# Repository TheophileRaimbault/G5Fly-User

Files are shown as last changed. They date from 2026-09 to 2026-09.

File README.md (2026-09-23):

# G5Fly NXP-MCXA154

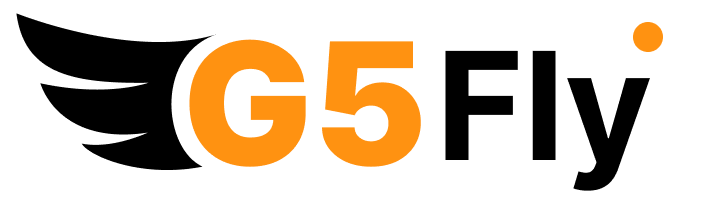
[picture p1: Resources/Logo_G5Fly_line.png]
G5Fly logo


Open-source GNSS navigation board for drones and robotics.

G5Fly is a compact board built around the Septentrio Mosaic-G5 module for lightweight UAV, robotics, and navigation projects. The repository contains the hardware design files, firmware sources, and supporting documentation needed to use the board, manufacture it, or create a custom derivative.

Author: <a href="https://github.com/TheophileRaimbault">Théophile Raimbault</a><br>
Maintainer: Septentrio GNSS GitHub user <githubuser@septentrio.com><br>
External website: https://github.com/septentrio-gnss/G5Fly<br>
License: <a href="https://creativecommons.org/licenses/by-sa/4.0/">Creative Commons Attribution-ShareAlike 4.0</a> and <a href="https://www.oshwa.org/definition/">Open Source Hardware</a><br>

<div style="background-color:#e3f2fd; border-left:5px solid #1976D2; padding:10px; border-radius:5px; margin-top:10px;">
  ℹ️ <strong>Note:</strong> G5Fly is optimized for a 30.5 x 30.5 mm FPV drone form factor and is intended for open source drone or robot projects.
</div><br>

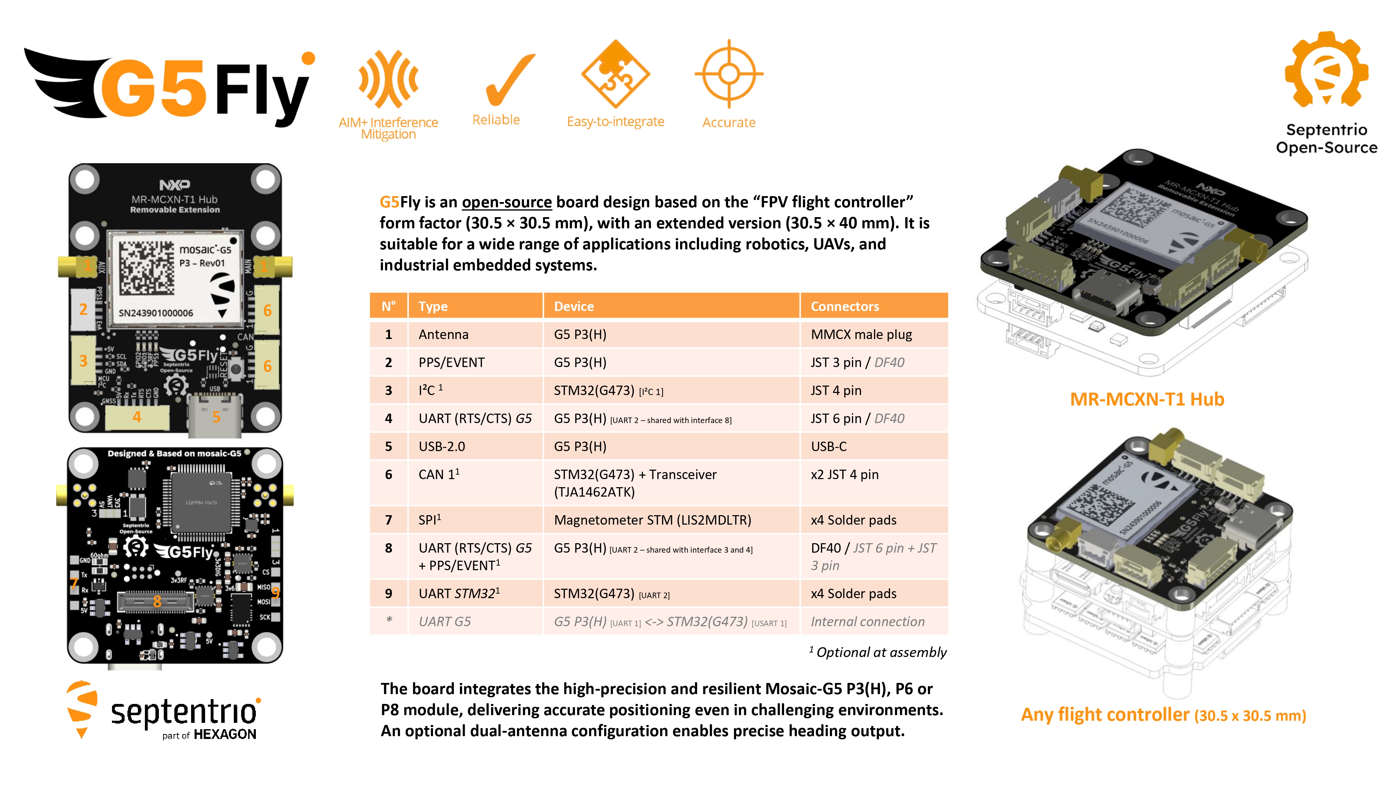
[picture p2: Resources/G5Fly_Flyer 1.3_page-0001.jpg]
<br>

## Who is this repository for?

This project serves two audiences:

- Users who want to buy, assemble, or use the board as-is.
- Designers who want to understand the hardware in detail and create a custom version.

If you are a user, start with the sections below. If you want to modify the design, go to [DESIGN.md](DESIGN.md).

## For users

### Key features
- Compact 30.5 x 30.5 mm FPV-friendly form factor
- Septentrio Mosaic-G5 GNSS receiver support
- USB and external 5 V power options
- DroneCAN, TTL, serial and I2C interfaces
- Reset input and status LEDs
- Mezzanine connection for the [NXP MCXN T1 hub](https://github.com/NXP-Robotics/mr_mcxn_t1_hub)

### Feature - Mezzanine integration with the NXP MCXN T1 hub

The G5Fly can be connected through its mezzanine interface to the [NXP MCXN T1 hub](https://github.com/NXP-Robotics/mr_mcxn_t1_hub). This provides a hardware expansion path for robotics applications. Refer to the [NXP integration HW-FW document](Resources/NXP%20integration%20HW-FW.pptx) for the hardware and firmware integration details.

<p align="center">
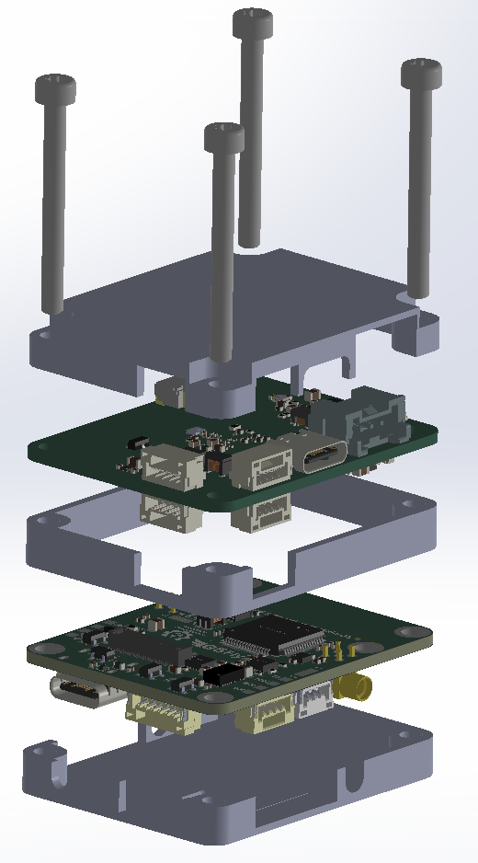
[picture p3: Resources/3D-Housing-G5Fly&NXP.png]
3D housing integrating the G5Fly and NXP MCXN T1 hub
  
</p>

### Quick start
1. Use the current production design files in [hardware/versions/v1/kicad/production](hardware/versions/v1/kicad/production/) if you want to build the board without changing the design.
2. Connect a suitable GNSS antenna and power the board through USB or an external 5 V source.
3. Develop and flash your application using the [Zephyr Project](https://www.zephyrproject.org/). No application software is currently provided by default.
4. Use the available UART, I2C, or DroneCAN interfaces depending on your integration target.
5. Validate the board with the status LEDs and the expected GNSS fix behavior before full integration.

### Antenna power selection
- Power can be supplied by USB or from an external 5 V rail.
- Active antennas must be powered at the voltage specified by the antenna manufacturer.

<div style="background-color:#ffebee; border-left:5px solid #c62828; padding:10px; border-radius:5px; margin:10px 0;">
  <strong>Warning:</strong> Solder <code>JP1</code> before using an active antenna. If the jumper is left open, the <code>VANT</code> net is not powered and the antenna may not work, causing a significant loss of GNSS performance. Select only one voltage, according to the antenna datasheet.
</div>

<table>
  <tr>
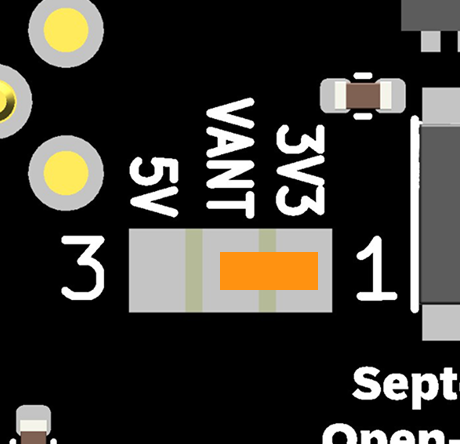
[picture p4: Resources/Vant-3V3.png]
JP1 configured for 3.3 V antenna power
    <td align="center"><br><strong>3.3 V antenna</strong><br>Connect <code>VANT</code> to <code>+3.3V_RF</code>.</td>
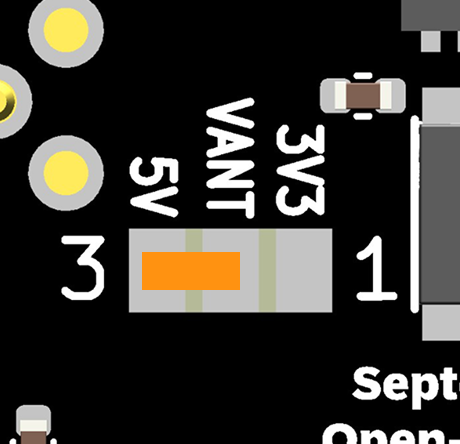
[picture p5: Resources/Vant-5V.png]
JP1 configured for 5 V antenna power
    <td align="center"><br><strong>5 V antenna</strong><br>Connect <code>VANT</code> to <code>+5V</code>.</td>
  </tr>
</table>

### Production and manufacturing
For a production build without hardware changes:

- Use the current KiCad project and generated manufacturing files from the hardware folder: [hardware/versions/v1/kicad](hardware/versions/v1/kicad/)
- Provide the manufacturer with the schematic, PCB files, BOM, and CPL.
- Verify antenna connector type, jumper configuration, and power options before assembly.
- Reference schematic: [Resources/G5Fly-schematics-NXP.pdf](Resources/G5Fly-schematics-NXP.pdf)

#### JLCPCB manufacturing requirements

- Keep the default KiCad PCB setup and its calculated impedance settings.
- Manufacture the board as a 6-layer PCB.
- `PCB Requirement: User.1 layer should be used as the V-cut guide layer.`
- Refer to the detailed [PCB rules](Resources/PCB_rules.png) when preparing or reviewing the PCB for production.
- For a production run at JLCPCB, use the [G5Fly_NXP_Rev-2_JLCPCB production archive](hardware/versions/v1/kicad/production/G5Fly_NXP_Rev-2_JLCPCB.zip), which contains the files prepared and previously submitted to JLCPCB for manufacturing.

### Power and antenna
- Keep GNSS antenna cables away from noisy power traces where possible.

### Recommended antenna options
The following antenna families are commonly considered for evaluation:

- D-Helix antenna HX-CHX600A
- D-Helix antenna HX-CH7609A
- HC990EXF Calian antenna

A SMA-to-MMCX adapter is often useful for compatibility with the board connector.

## For designers and contributors

The detailed hardware design guide is available in [DESIGN.md](DESIGN.md).

That document covers:
- Overall architecture and major blocks
- Component selection and board organization
- How to create a custom derivative board
- Manufacturing and validation recommendations
- Suggested workflows for changing the hardware safely

## Repository structure
- [hardware](hardware): PCB sources, KiCad projects, and mechanical assets
- [firmware](firmware): firmware and configuration files
- [Resources](Resources): images, schematics, and support documents
- [docs](docs): additional notes and guidance

## Licensing
This project is released under the Creative Commons Attribution-ShareAlike 4.0 license and follows the Open Source Hardware definition.

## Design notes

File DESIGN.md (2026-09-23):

# G5Fly NXP-MCXA154 hardware design guide

This document is for contributors who need to understand or modify the NXP hardware design.

## 1. Purpose of this document

Use this guide to locate the important hardware references, modify the KiCad project, and prepare a checked production release.

## 2. Project overview

G5Fly is a 30.5 x 30.5 mm GNSS board built around the Septentrio mosaic-G5 and an NXP MCXA154. The MCXA154 is intended to run a user application built with Zephyr; no application firmware is supplied by default.

## 3. Repository structure

Start with these locations:

- [hardware/versions/v1/kicad](hardware/versions/v1/kicad): the current KiCad project
- [hardware/versions/v1/kicad/production](hardware/versions/v1/kicad/production): production exports
- [hardware/common/libraries](hardware/common/libraries): project symbols, footprints, and 3D models
- [hardware/common/design_rules/design-rules.md](hardware/common/design_rules/design-rules.md): track, via, and clearance values
- [Resources/G5Fly-schematics-NXP.pdf](Resources/G5Fly-schematics-NXP.pdf): schematic PDF
- [VERSIONING.md](VERSIONING.md): changes between hardware revisions

## 4. Hardware architecture
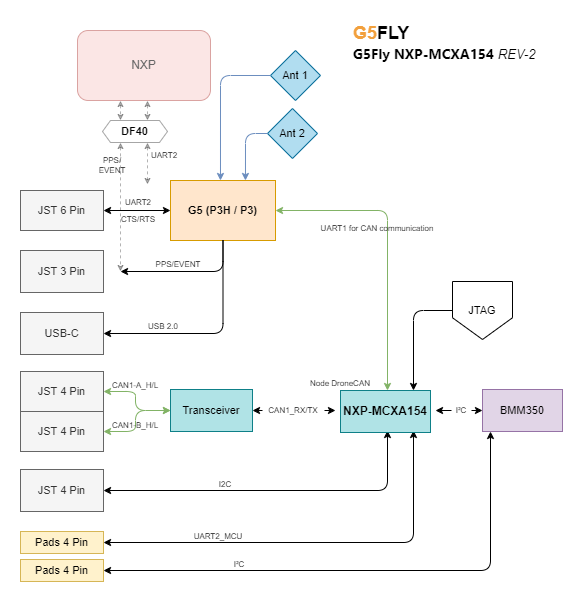
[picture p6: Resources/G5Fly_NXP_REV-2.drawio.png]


*Functional block diagram of the G5Fly NXP-MCXA154 REV-2, showing the Mosaic-G5 receiver, MCXA154, BMM350 magnetometer, CAN transceiver, antenna connections, and the main UART, I2C, PPS, USB, and expansion interfaces.*

### 4.1 Main functional blocks

The board can be understood through the following main components. Their references correspond to the [G5Fly NXP Rev-2 BOM](hardware/versions/v1/kicad/production/G5Fly_NXP_Rev-2_bom.csv):

| Function | Reference | Component | Role |
| --- | --- | --- | --- |
| GNSS receiver | `U1` | Septentrio mosaic-G5 | Main GNSS receiver |
| Microcontroller | `IC1` | NXP MCXA154VLH | Runs the Zephyr application |
| Magnetometer | `U4` | Bosch BMM350 | Magnetic-field measurement |
| CAN transceiver | `U3` | NXP TJA1462ATK | Physical-layer interface for DroneCAN/CAN |
| Main power regulation | `U8` | MPM3632CGQV-Z | Main switching regulator |
| Low-noise regulation | `U7`, `U12` | TPS7A9401DSCR | Low-noise regulated power rails |
| Antenna power selection | `JP1` | 3-position solder jumper | Selects antenna power between `+3.3V_RF` and `+5V` |

### 4.2 Connectors and configuration points

The board exposes the following connectors and configuration points. Their references correspond to the schematic and the [G5Fly NXP Rev-2 BOM](hardware/versions/v1/kicad/production/G5Fly_NXP_Rev-2_bom.csv):

| Interface or function | Reference | Connector or component | Role |
| --- | --- | --- | --- |
| PPS and event interface | `J1` | JST-SM03B-GHS | Ground, PPS input and event signal |
| GNSS serial interface | `J4` | JST-SM06B-GHS | GNSS UART, 5 V power and ground |
| Magnetometer interface | `J7` | JST-SM04B-GHS | I2C connection to the magnetometer or an external sensor |
| CAN interface | `J6`, `J9` | JST-SM04B-GHS | DroneCAN/CAN connection and power |
| Main GNSS antenna | `J10` | MMCX connector | Main antenna RF connection |
| Auxiliary GNSS antenna | `J11` | MMCX connector | Auxiliary antenna RF connection |
| USB | `J3` | USB-C receptacle | USB communication and board power |
| Mezzanine expansion | `J8` |  [DF40 board-to-board connector](Resources/Connector-DF40.png)| High-density expansion interface  |
| Programming and debug | `J5` | Tag-Connect TC2030 | SWD programming and debug access |
| Antenna power selection | `JP1` |  [3-position solder jumper](Resources/Vant-5V.png)| Selects antenna power between `+3.3V_RF` and `+5V` |
| Reset | `SW3` | Push button | Resets the MCXA154 |

## 5. Modification workflow

### Step 1: Create a new hardware revision

Copy [hardware/versions/v1](hardware/versions/v1) to a new revision directory before making a hardware change. Keep released revisions unchanged. Record the change in [VERSIONING.md](VERSIONING.md).

### Step 2: Change the schematic first

Open `hardware/versions/v1/kicad/G5FLY.kicad_pro` and modify `G5FLY.kicad_sch` before editing the PCB. For every changed component, check its pin mapping, footprint, value, and datasheet. Pay particular attention to the GNSS RF path, `VANT`, the MCXA154 pin assignment, the I2C magnetometer bus, and the CAN transceiver.

### Step 3: Update and review the PCB

Update the PCB from the schematic, then review the board outline, connector orientation, antenna connectors, magnetometer orientation, copper clearances, and power paths. Do not replace project-library parts with global KiCad libraries; follow [Guidline.md](Guidline.md).

### Step 4: Run checks before export

Run ERC on the schematic and DRC on the PCB. Resolve errors, or document an intentional exception before continuing. Confirm that the schematic, PCB, BOM, and designators describe the same revision.

### Step 5: Prepare production files

Before sending the board for manufacturing, prepare:

- schematic export or PDF,
- KiCad project archive or source files,
- BOM,
- CPL/placement file,
- Gerbers and drill files,
- assembly notes for connectors, jumpers, and antennas.

<div style="background-color:#fff8e1; border-left:5px solid #f9a825; padding:10px; border-radius:5px; margin-top:10px;">
	<strong>Tip:</strong> It is recommended to use the KiCad Fabrication Toolkit to extract the fabrication files, including the Fab BOM and CPL, in the format required for production by JLCPCB.
</div>

## 6. Checks specific to this board

### 6.1 RF and antenna layout

- keep the antenna path short and direct,
- keep switching and high-speed digital traces away from the GNSS RF path,
- verify the two MMCX connectors (`J10` and `J11`) and their ground connection,
- antenna power is routed through pad 2 of `JP1` on the `VANT` net; `JP1` selects `+3.3V_RF` or `+5V`.

<div style="background-color:#ffebee; border-left:5px solid #c62828; padding:10px; border-radius:5px; margin:10px 0;">
	<strong>Warning:</strong> JP1 must be soldered for the required antenna voltage. If the jumper is left open, the <code>VANT</code> net is not powered and an active antenna may not work, causing a significant loss of GNSS performance.
</div>

The solder bridge must connect the centre `VANT` pad to the voltage required by the antenna. Select only one configuration, according to the antenna datasheet:

<table>
	<tr>
		<td align="center">JP1 configured for 3.3 V antenna power<br><strong>3.3 V antenna</strong><br>Solder the bridge between `VANT` and `+3.3V_RF`.</td>
		<td align="center">JP1 configured for 5 V antenna power<br><strong>5 V antenna</strong><br>Solder the bridge between `VANT` and `+5V`.</td>
	</tr>
</table>

- verify the selected antenna voltage against the antenna datasheet before assembly.

### 6.2 Power integrity

- preserve the existing separation between digital, RF, and low-noise regulated rails,
- verify the ratings and output voltages of `U8`, `U7`, and `U12` after any power-tree change,
- check the USB and external 5 V paths for reverse-current or short-circuit risks,
- use the track widths and via sizes defined in [design-rules.md](hardware/common/design_rules/design-rules.md).

### 6.3 Mechanical integration

- preserve the 30.5 x 30.5 mm board outline unless creating a new derivative,
- confirm clearance around `J3`, `J8`, `J10`, and `J11`,
- keep the magnetometer clear of ferromagnetic parts and high-current paths,
- check connector access against the intended enclosure or frame.

## 7. Release checklist

Before sending a revision to production:

- confirm the revision identifier and update [VERSIONING.md](VERSIONING.md),
- run schematic ERC and PCB DRC,
- verify that every schematic component has a project-library symbol and footprint,
- verify that all 3D models use relative paths,
- compare the BOM and designator list with the final schematic and PCB,
- inspect `J3`, `J5`, `J6`, `J7`, `J8`, `J9`, `J10`, `J11`, `JP1`, and `SW3`,
- verify antenna power selection and connector orientation,
- generate Gerbers, drill files, Fab BOM, and CPL with the Fabrication Toolkit,
- open the generated files or use the manufacturer preview before ordering,
- record the validation result and any intentional exceptions.

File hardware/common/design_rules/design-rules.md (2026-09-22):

Track width :

    Power : 0.5
    Smal Power : 0.3
    Signal : 0.2

Via size :

    hole : 0.3
    size : 0.5

Change applied : 

    Minimum Track width: 0.25 to 0.15
    Minimum annular width : 0.2 to 0.15
    Coper to eadge Clearance : 0.3 to 0.2

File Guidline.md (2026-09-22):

***

# Library Management

## Overview

All project components are centralized in a single library to ensure portability, reproducibility, and ease of maintenance.

```
hardware/common/libraries/
├── symbols/
│   └── G5FLY.kicad_sym
└── footprints/
    └── G5FLY.pretty/
```

All symbols and footprints used in the project must be defined in these libraries.  
External or global KiCad libraries must not be used.

***

## Adding a New Component

When introducing a new component (e.g., from JLCPCB, SnapEDA, UltraLibrarian), follow the process below.

### 1. Import and Validate

Import the symbol and footprint using the preferred method.  
Verify correctness before integration:

* Pin mapping
* Orientation
* Footprint dimensions
* Datasheet consistency

***

### 2. Add Symbol to Project Library

1. Open the Symbol Editor
2. Open the project library:
   ```
   G5FLY.kicad_sym
   ```
3. Open the imported symbol
4. Copy the symbol and paste it into `G5FLY.kicad_sym`

The library already exists; new components must be added to it, not recreated.

Apply a consistent naming convention:

```
R_10k_0603
C_100nF_0603
STM32G0_QFN32
USB_C_Receptacle
```

***

### 3. Add Footprint to Project Library

1. Open the Footprint Editor
2. Open the project footprint library:
   ```
   G5FLY.pretty
   ```
3. Copy the footprint and paste it into this library

Ensure consistency between symbol and footprint naming.

***

### 4. Add and Link 3D Model

All 3D models must be stored in:

```
hardware/common/3d_models/
```

Link the 3D model in the footprint using a relative path:

```
${KIPRJMOD}/../../../common/3d_models/component.step
```

Absolute paths must not be used.

***

### 5. Link Symbol, Footprint, and Fields

Ensure that:

* The symbol references the correct footprint
* The footprint references the correct 3D model
* Manufacturer or supplier fields are properly defined (e.g., LCSC ID)

***

### 6. Verify Library Consistency

In the schematic editor:

```
Tools → Edit Symbol Library Links
```

All components must reference:

```
G5FLY_lib
```

In the PCB editor:

```
Tools → Edit Footprint Library Links
```

Only the project footprint library should be used.

***

## Design Rules

The following rules apply to all components:

* Do not use global KiCad libraries (e.g., Device, Connector)
* Do not use absolute file paths
* Do not reference external plugin libraries directly
* Always copy components into the project libraries before use

***

# Version Management

## Directory Structure

Each hardware revision is stored independently:

```
hardware/versions/
├── v1/
├── v2/
└── v3/
```

Each version contains:

* KiCad project files
* Fabrication outputs
* Assembly notes
* Visual outputs

***

## Versioning Policy

### Immutable Releases

Released versions must not be modified after fabrication or validation.

Any change must result in a new version.

***

### Creating a New Version

To create a new revision:

```
cp -r v1 v2
```

All design modifications must be performed in the new version directory.

***

### Git Versioning

Each hardware revision must be tagged in Git:

```
v1.0
v2.0
```

Tags must correspond to manufacturable PCB versions.

***

### Recommended Workflow

* `main`: stable and released versions
* `dev`: ongoing development

Example:

```
git checkout -b dev
git commit -m "fix: correct pull-up resistor value"
git commit -m "feat: add ESD protection"
```

When ready:

```
git checkout main
git merge dev
git tag v2.0
```

***

## Fabrication Outputs

Each version must include complete manufacturing data:

```
fabrication/
├── gerbers/
├── bom/
├── pick_place/
```

This ensures that any version can be reproduced without ambiguity.

***

## Objective

The repository must guarantee that any user can:

```
git clone
open project in KiCad
generate outputs
manufacture the board
```

and obtain identical hardware.

***

## Summary

* Single, centralized project library
* No external dependencies
* Fully versioned hardware revisions
* Reproducible and traceable fabrication data
* Consistent and maintainable structure for long-term development

***

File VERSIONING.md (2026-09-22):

# Versioning and change log

This document summarizes the main hardware changes between G5Fly revisions.

## REV1 -> REV2

The following changes were applied for the transition from REV1 to REV2:

### Mechanical and layout
- Increased the spacing between the connector and the screw hole.
- Reduced the board size slightly to better match the NXP board footprint.
- Added the REV-1 reference on the silkscreen.
- Adjusted the LED spacing.

### Electrical and component updates
- Changed the I2C pull-up resistors to a more suitable value range (from 10 kΩ to a more appropriate 2.2–4.7 kΩ range).
- Corrected the main antenna grounding connection.
- Replaced the wrong resistor value R16 from 24 kΩ to 13 kΩ for production.
- Switched the magnetometer interface from SPI to I2C.
- Changed the CAN termination approach to a shunt-based solution.
- Updated the magnetometer component used for the NXP board compatibility.

### Connectors and interfaces
- Changed to the correct Hirose connector part number: DF40TC(2.5)-50DS-0.4V(51).
- Removed unused STM32 CTS/RTS pins from the schematic.
- Added a PPS signal from the GNSS to the STM32 for time synchronization.
- Added a CAN status LED.

### Firmware and identification
- Added an internal crystal oscillator.
- Added hardware board ID information in the ArduPilot board definition file.
- Added silkscreen orientation guidance for the magnetometer.

### Not implemented in REV2
The following ideas were considered but were not implemented in REV2:
- reversed diode protection,
- adding a reset button or reset pin for the G5,
- adding additional flash memory.

## Future versioning guidance

For each new revision, it is recommended to keep this file updated with:

- the revision number,
- the date or milestone,
- a short summary of the main changes,
- the list of items intentionally not implemented,
- any important impact on firmware or integration.

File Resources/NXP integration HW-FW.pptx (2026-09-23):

## G5Fly integration with NXP

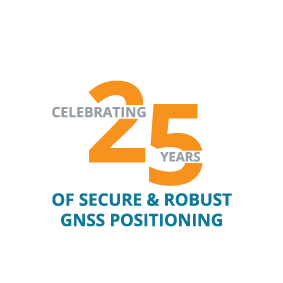
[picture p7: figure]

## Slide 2

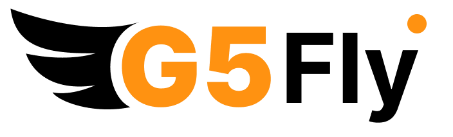
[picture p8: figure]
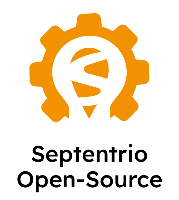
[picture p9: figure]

Hardware Integration with NXP

FPV GNSS based on NXP MCU

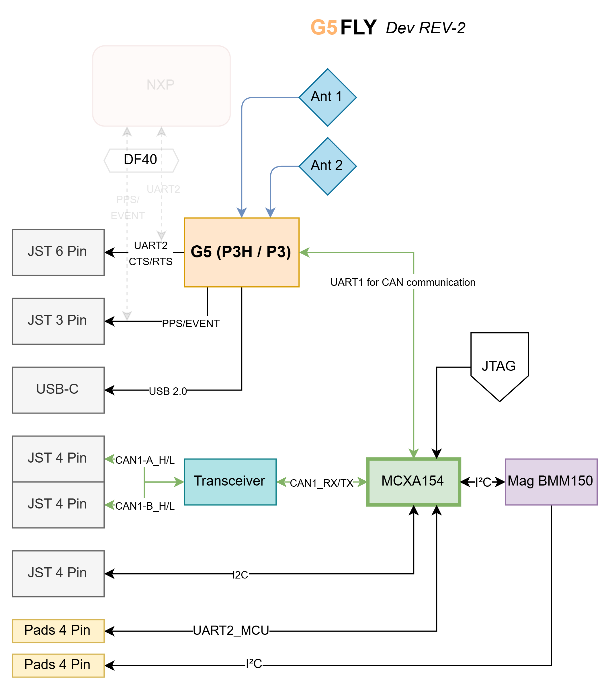
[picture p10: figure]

GNSS Tool for NXP MR-MCXN-T1 Hub

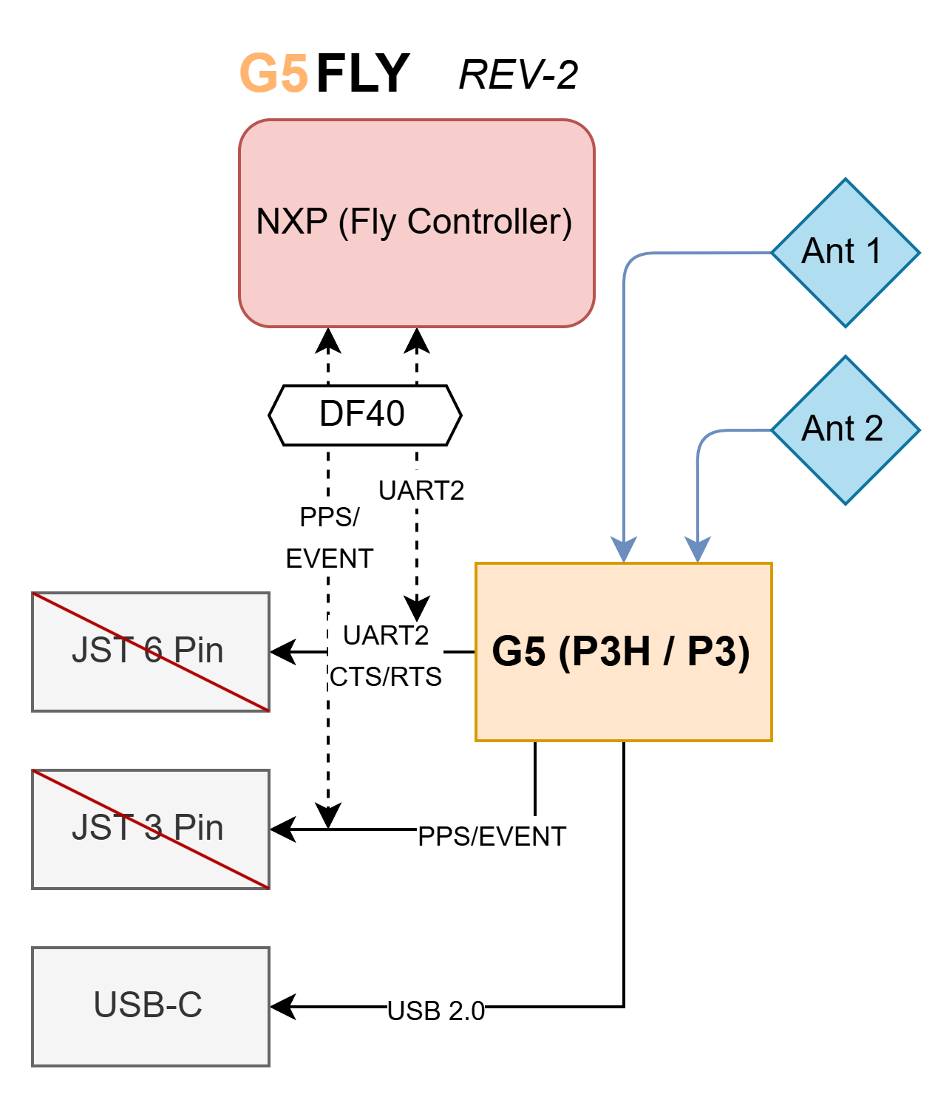
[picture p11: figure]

Unmonted component for MR-MCXN-T1 Hub

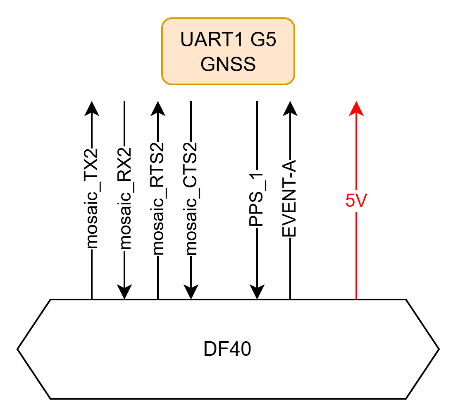
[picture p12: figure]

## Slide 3

Software Integration with NXP

FPV GNSS based on NXP MCU

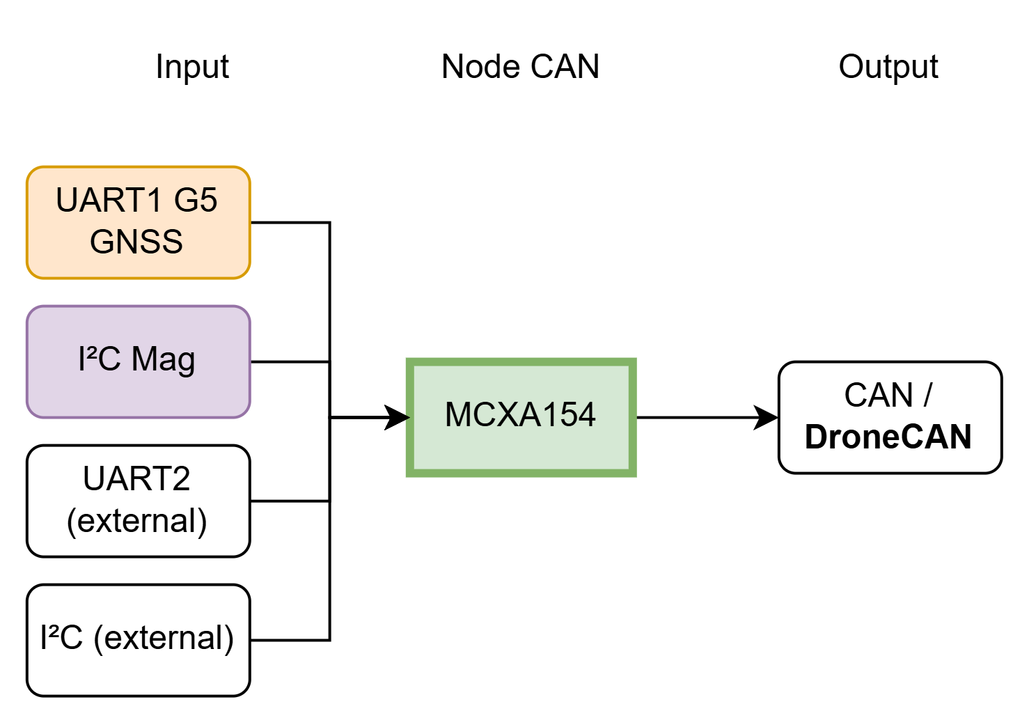
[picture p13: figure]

Need software capable of managing DroneCAN with SBF or NMEA + I²C Mag + other possible sensor inputs

GNSS Tool for NXP MR-MCXN-T1 Hub

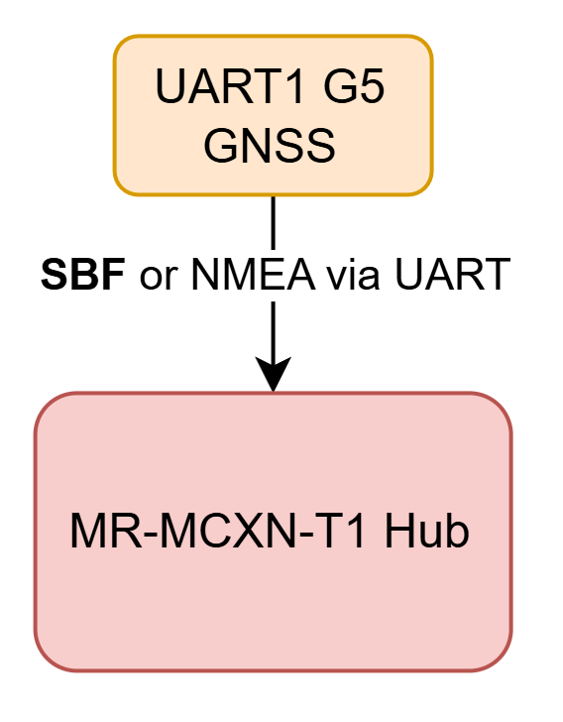
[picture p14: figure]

Need software capable of managing SBF or NMEA via UART

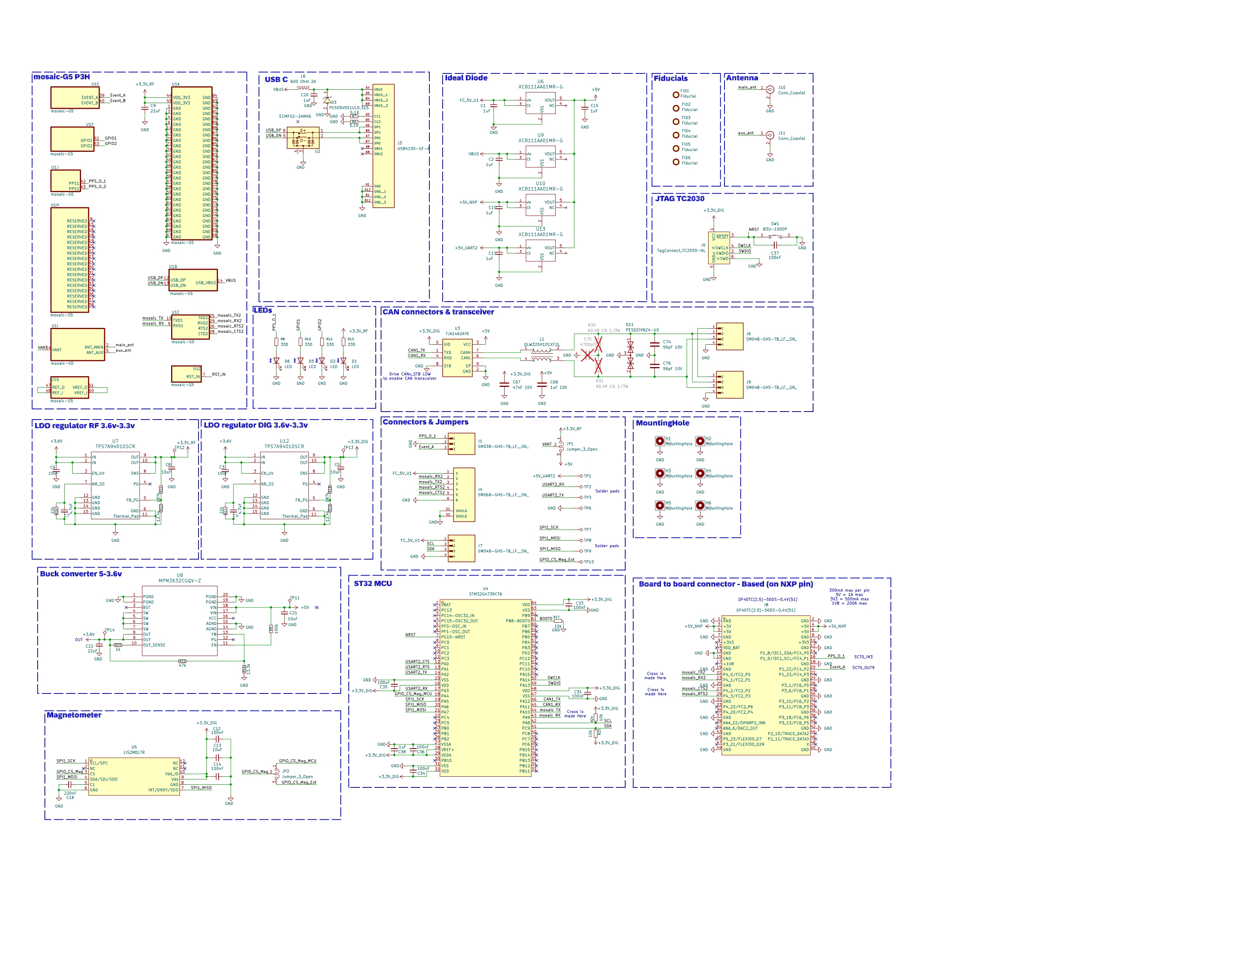
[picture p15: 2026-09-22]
Resources/G5Fly-schematics.jpg

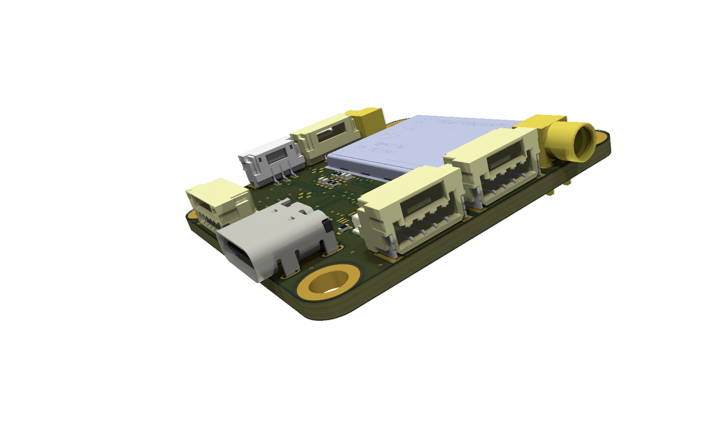
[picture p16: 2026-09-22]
Resources/G5FLY-3D-2.png

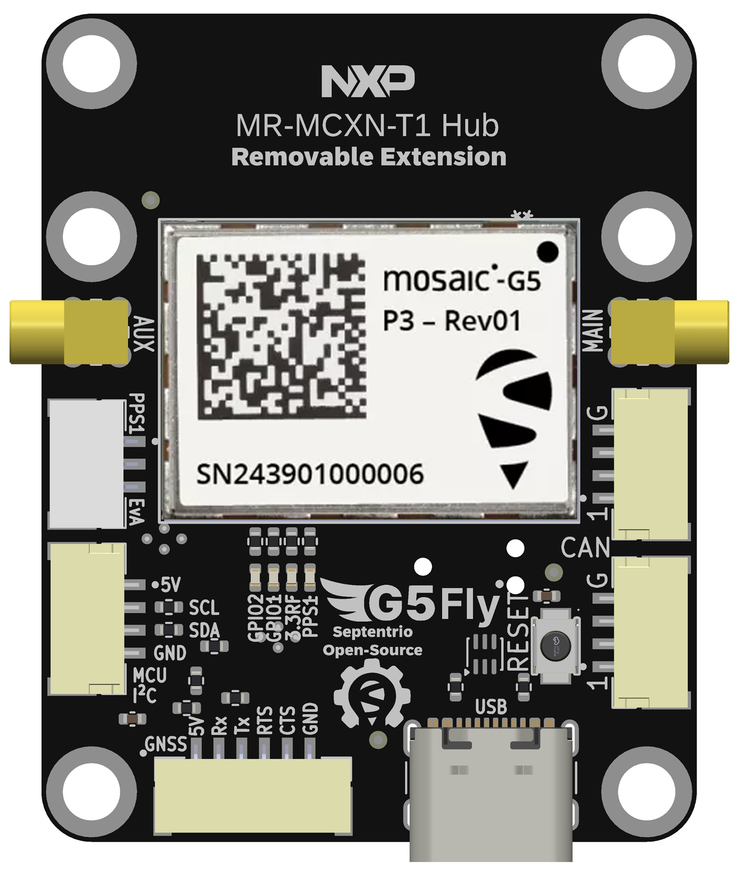
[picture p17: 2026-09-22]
Resources/Top_black_G5Fly.png

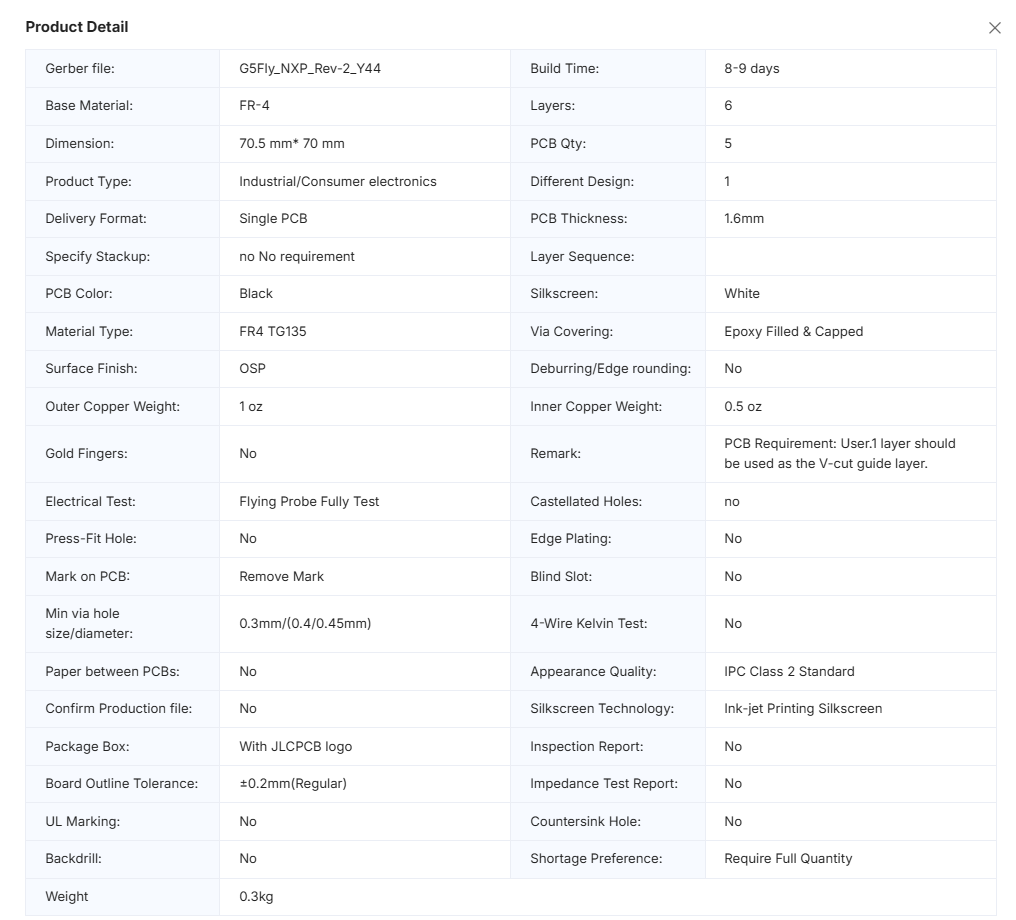
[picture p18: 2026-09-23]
Resources/PCB_rules.png

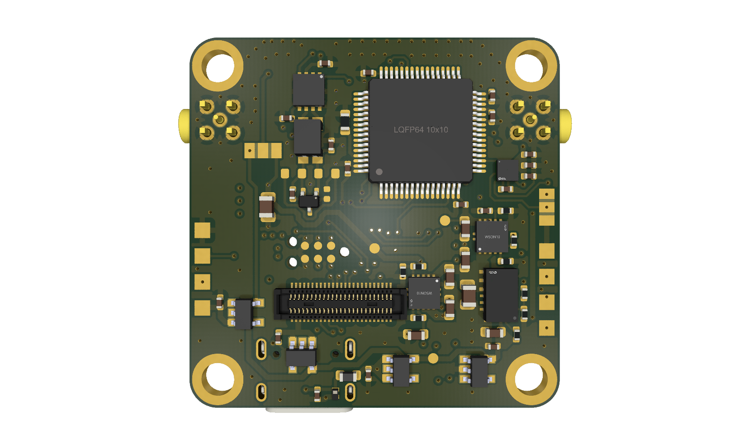
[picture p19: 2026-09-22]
Resources/G5FLY-Bot-ray.png

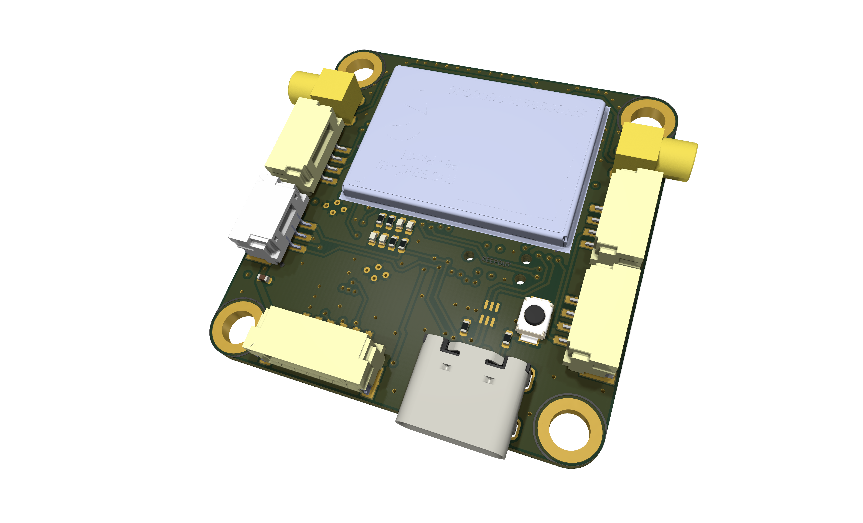
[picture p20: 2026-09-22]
Resources/G5FLY-3D.png

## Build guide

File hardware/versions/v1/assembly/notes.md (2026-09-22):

Placeholder for hardware/versions/v1/assembly/notes.md

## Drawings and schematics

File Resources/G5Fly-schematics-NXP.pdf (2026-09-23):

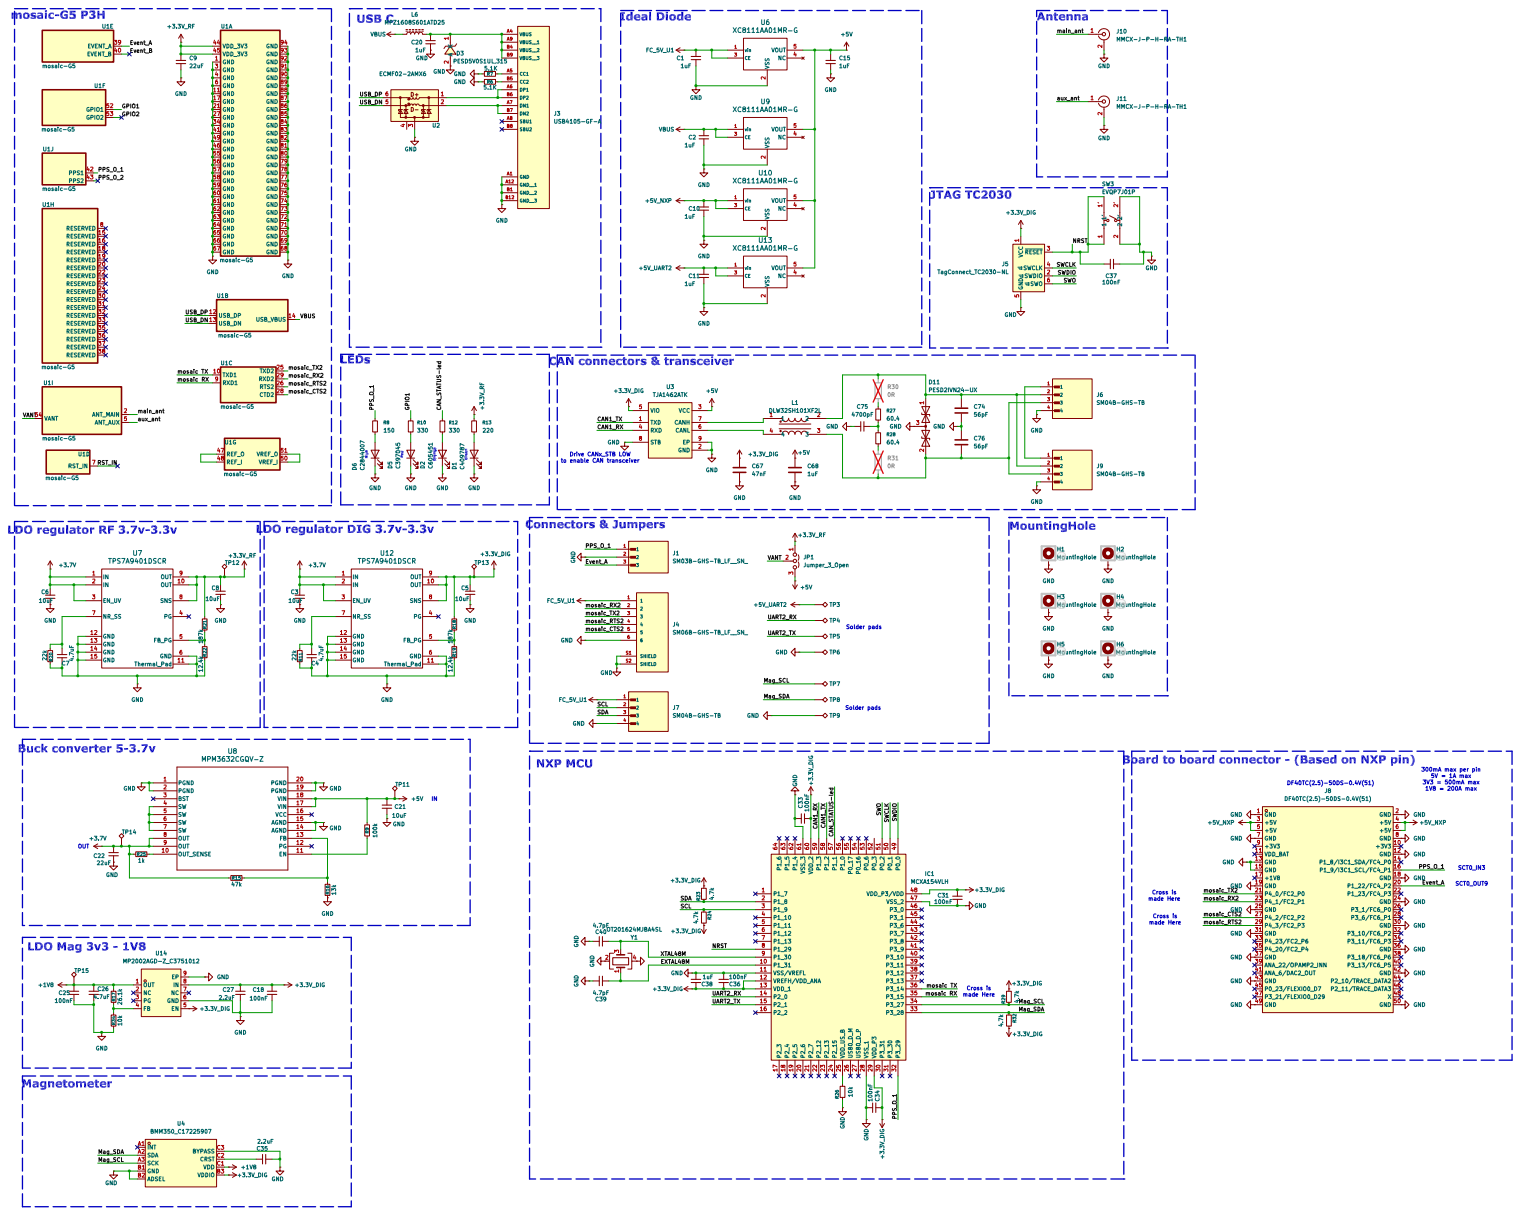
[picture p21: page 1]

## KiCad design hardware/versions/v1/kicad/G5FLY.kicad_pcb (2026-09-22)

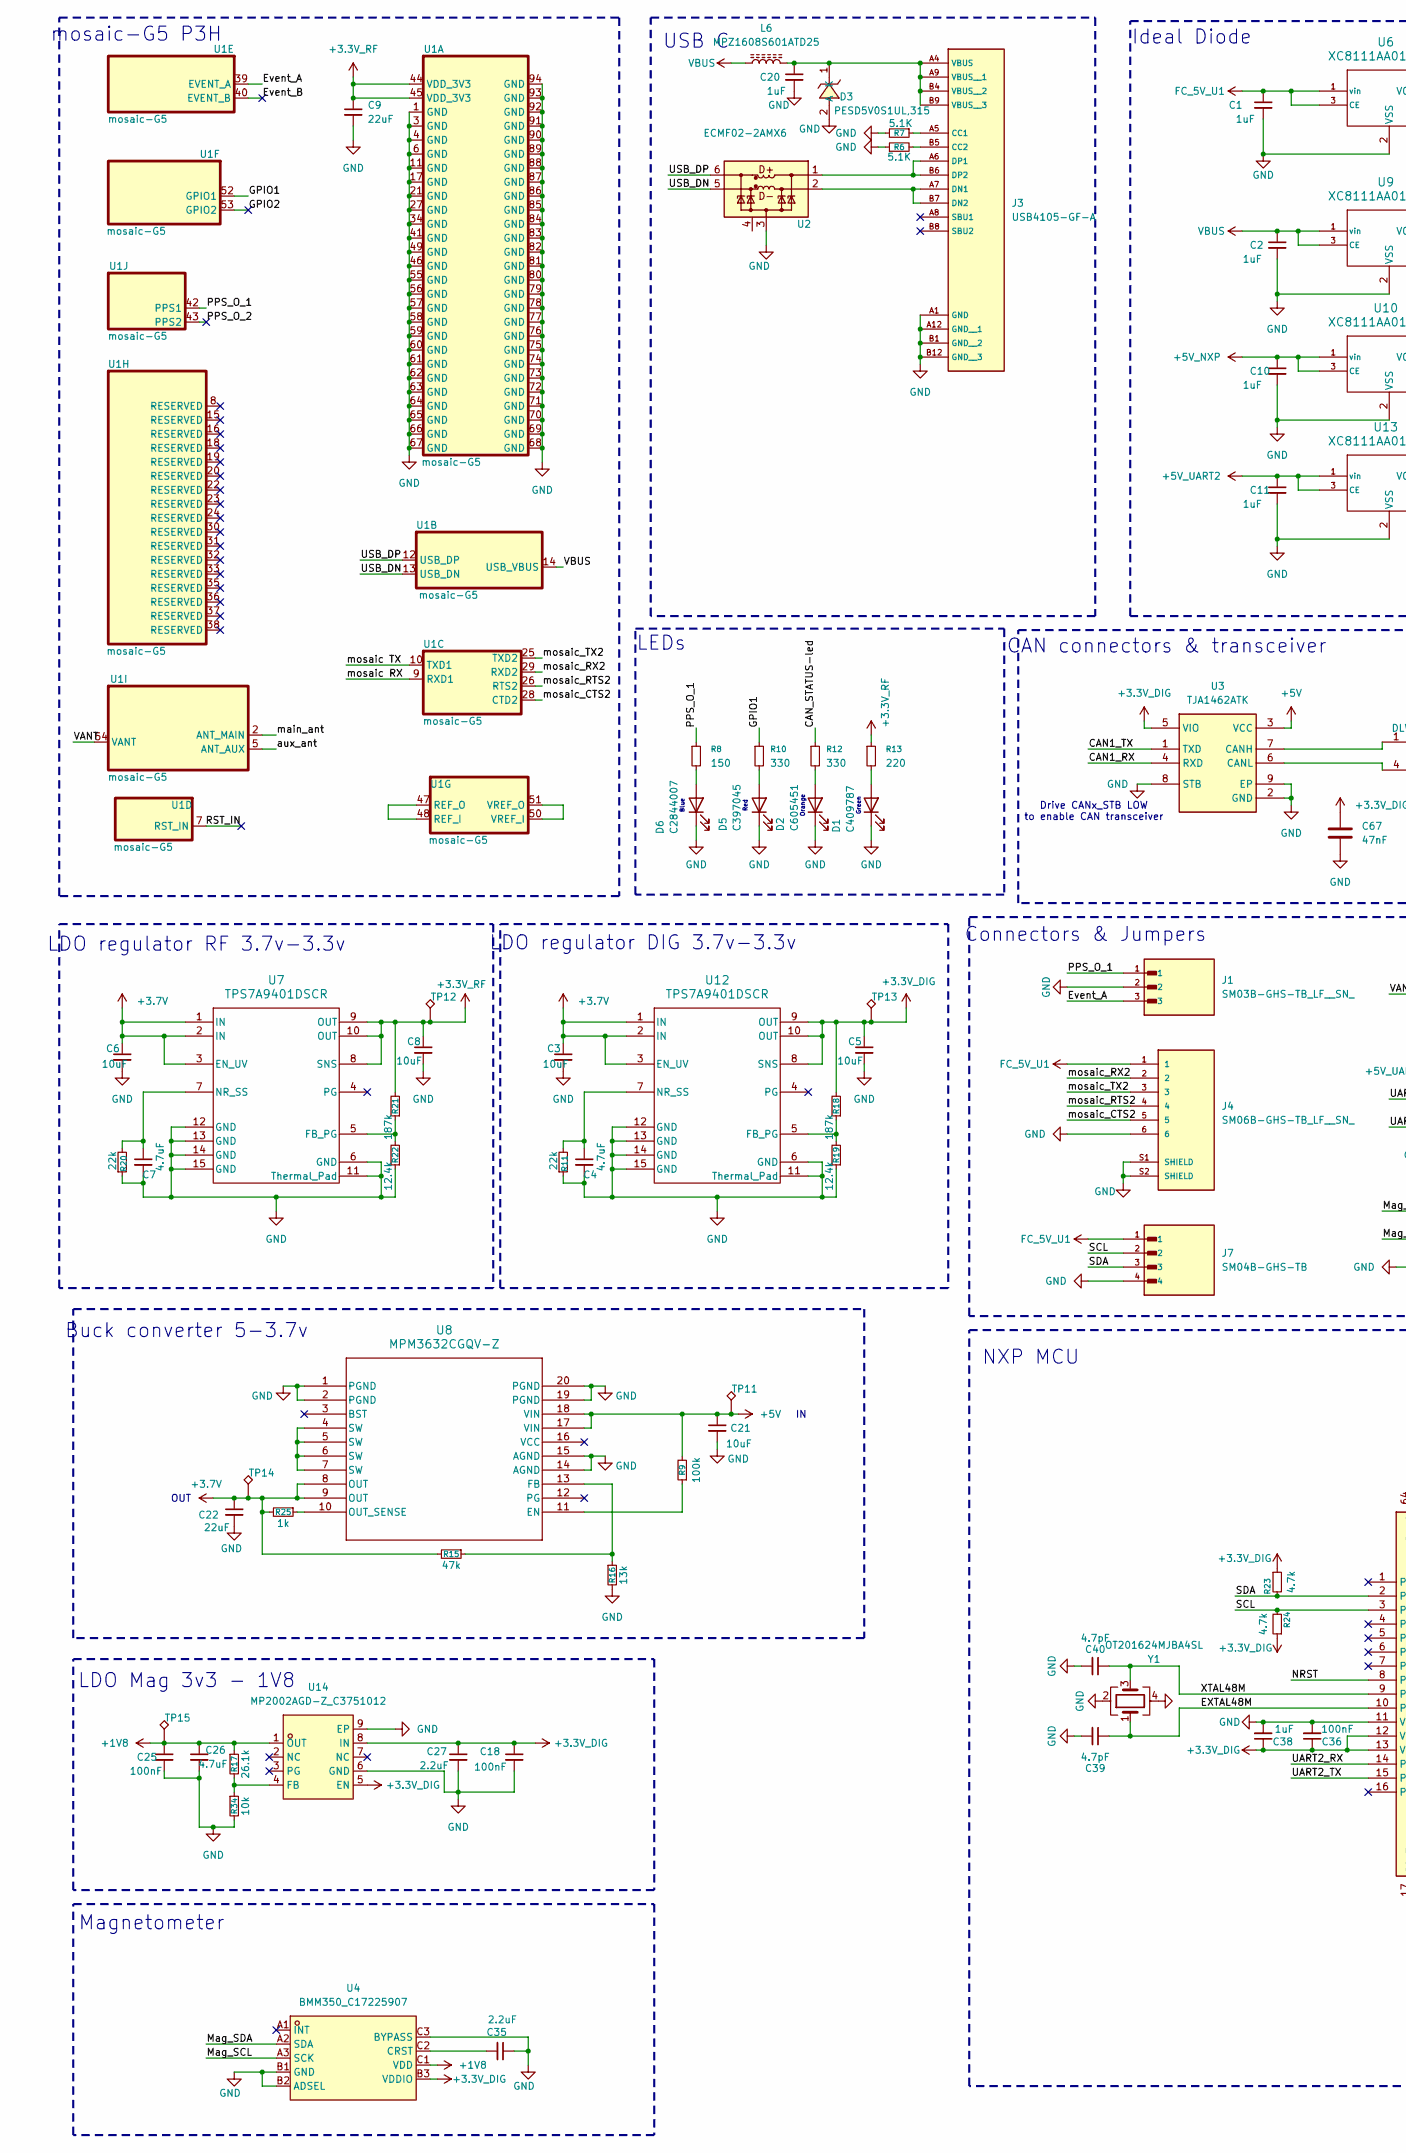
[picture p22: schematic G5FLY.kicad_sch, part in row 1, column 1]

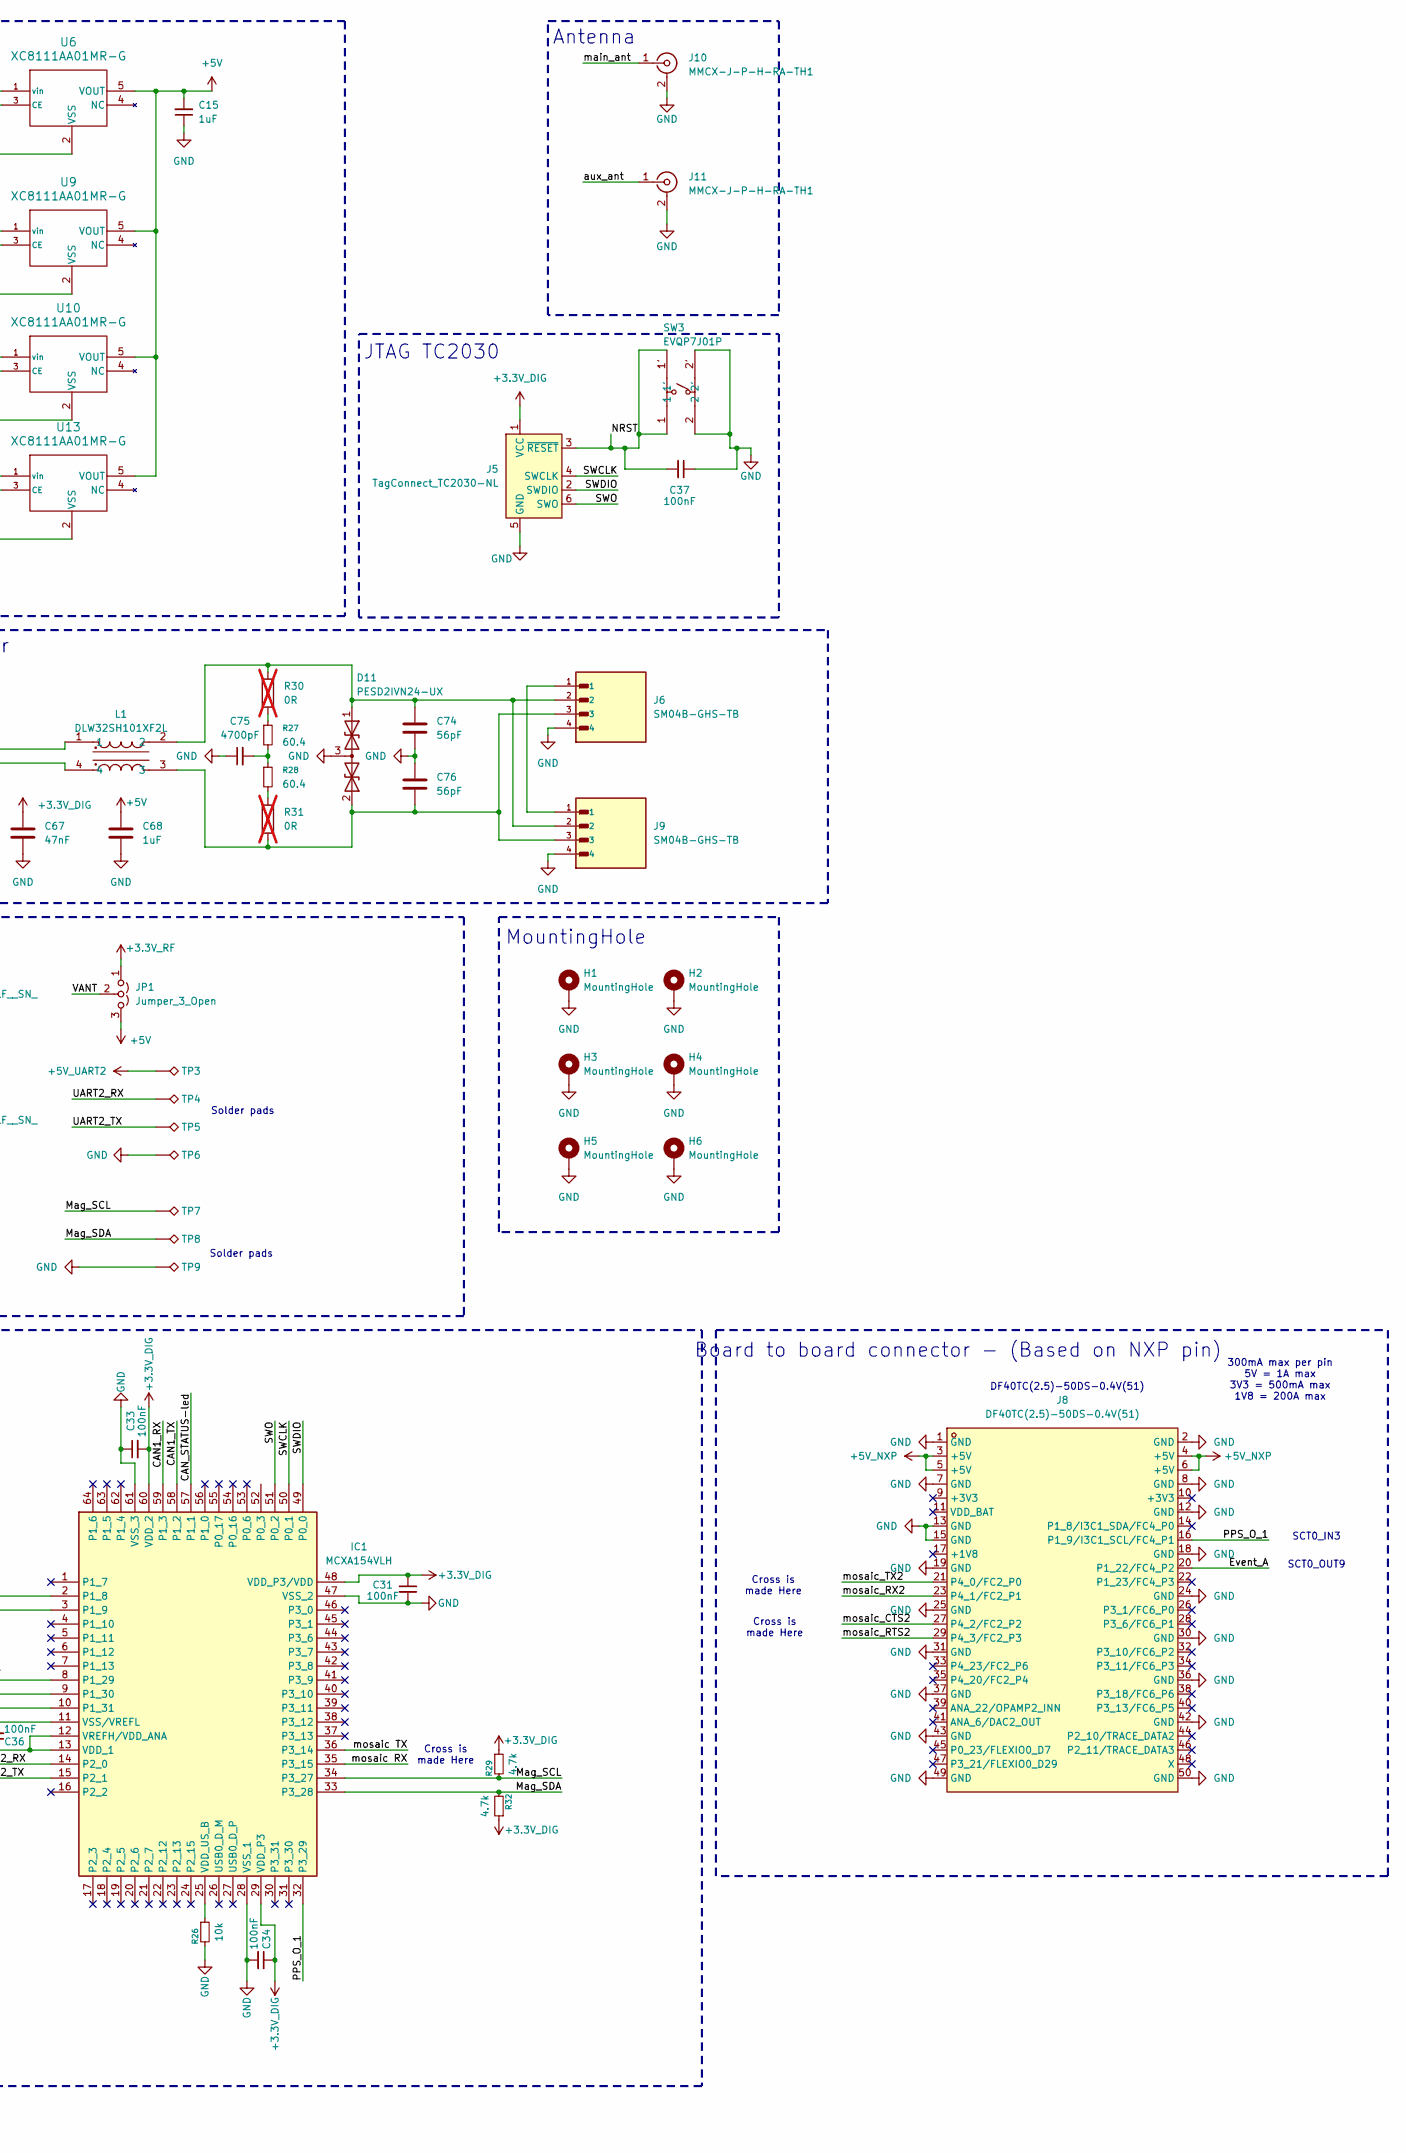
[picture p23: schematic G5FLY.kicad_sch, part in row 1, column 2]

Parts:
C1, C2, C10, C11, C15, C20, C38: 1uF; C_0402_1005Metric
C3, C5, C6, C8, C21: 10uF; C_0603_1608Metric
C4, C26: 4.7uF; C_0402_1005Metric
C7: 4.7uF; C_0603_1608Metric
C9, C22: 22uF; C_0805_2012Metric
C18, C25, C31, C33, C34, C36, C37: 100nF; C_0402_1005Metric
C27, C35: 2.2uF; C_0402_1005Metric
C39, C40: 4.7pF; C_0402_1005Metric
C67: 47nF; C_0402_1005Metric; JLCPCB C77012
C68: 1uF; C_0402_1005Metric; JLCPCB C528974
C74, C76: 56pF; C_0402_1005Metric; JLCPCB C107007
C75: 4700pF
D1: C409787; LED_0402_1005Metric; JLCPCB C409787
D2: C605451; LED_0402_1005Metric; JLCPCB C605451
D3: PESD5V0S1UL,315; SOD-882_L1.0-W0.6-RD; MPN PESD5V0S1UL,315; LCSC Part C85402
D5: C397045; LED_0402_1005Metric; JLCPCB C397045
D6: C2844007; LED_0402_1005Metric; JLCPCB C2844007
D11: PESD2IVN24-UX; SOT-323_SC-70; JLCPCB C552496
H1, H2, H3, H4, H5, H6: MountingHole; MountingHole_3.2mm_M3_DIN965_Pad
IC1: MCXA154VLH; QFP50P1200X1200X160-64N; Manufacturer_Part_Number MCXA154VLH
J1: SM03B-GHS-TB_LF__SN_; JST_SM03B-GHS-TB_LF__SN_
J3: USB4105-GF-A; USB_C_Receptacle_GCT_USB4105-xx-A_16P_TopMnt_Horizontal
J4: SM06B-GHS-TB_LF__SN_; JST_SM06B-GHS-TB_LF__SN_; PARTREV N/A
J5: TagConnect_TC2030-NL; Tag-Connect_TC2030-IDC-NL_2x03_P1.27mm_Vertical
J6, J7, J9: SM04B-GHS-TB; JST_SM04B-GHS-TB_LF__SN_
J8: DF40TC(2.5)-50DS-0.4V(51); CONN-SMD_DF40C-50DS-0.4V51; MPN DF40C-50DS-0.4V(51); LCSC Part C424646
J10, J11: MMCX-J-P-H-RA-TH1; SAMTEC_MMCX-J-P-H-RA-TH1; JLCPCB C2934607
JP1: Jumper_3_Open; SolderJumper-3_P1.3mm_Open_Pad1.0x1.5mm_NumberLabels
L1: DLW32SH101XF2L; FILTER-SMD_4P-L3.2-W2.5-BL_DLW32SH510XK2L; MPN DLW32SH101XF2L; LCSC Part C1857795
L6: MPZ1608S601ATD25; L_0603_1608Metric; DigiKey 445-MPZ2012S601ATD25CT-ND
R6, R7: 5.1K; R_0402_1005Metric
R8: 150; R_0402_1005Metric
R9: 100k; R_0402_1005Metric
R10, R12: 330; R_0402_1005Metric
R11, R20: 22k; R_0402_1005Metric
R13: 220; R_0402_1005Metric
R15: 47k; R_0402_1005Metric
R16: 13k; R_0402_1005Metric
R17: 26.1k; R_0402_1005Metric
R18, R21: 187k; R_0402_1005Metric
R19, R22: 12.4k; R_0402_1005Metric
R23, R24, R29, R32: 4.7k; R_0402_1005Metric
R25: 1k; R_0402_1005Metric
R26, R34: 10k; R_0402_1005Metric
R27, R28: 60.4; R_0402_1005Metric
R30, R31: 0R; R_0603_1608Metric; DigiKey 541-60.4SCT-ND; not fitted
SW3: EVQP7J01P; SW-SMD_EVQP7J01P; MPN EVQP7J01P; LCSC Part C2828254
TP3, TP4, TP5, TP6, TP7, TP8, TP9: TestPoint_Alt; TestPoint_Pad_1.5x1.5mm
TP11, TP12, TP13, TP14, TP15: TestPoint_Alt; TestPoint_Pad_D1.0mm
U1: mosaic-G5; LGA54_MOSAIC-MINI_SEP
U2: ECMF02-2AMX6; ST_UQFN-6L_1.5x1.7mm_P0.5mm
U3: TJA1462ATK; SON65P300X300X100-9N-D; JLCPCB C3229259
U4: BMM350_C17225907; WLCSP-9_L1.3-W1.3-R3-C3-P0.40-TL; MPN BMM350; LCSC Part C17225907
U6, U9, U10, U13: XC8111AA01MR-G; IC_XC8111AA01MR-G
U7, U12: TPS7A9401DSCR; DSC0010J-MFG
U8: MPM3632CGQV-Z; QFN3p0x5p0x1p6_MPM3632C_MNP
U14: MP2002AGD-Z_C3751012; QFN-8_L2.1-W3.1-P0.50-TL-EP; MPN MP2002AGD-Z; LCSC Part C3751012
Y1: OT201624MJBA4SL; Crystal_SMD_2016-4Pin_2.0x1.6mm; JLCPCB C725986

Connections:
+1V8: C25.1, C26.1, R17.1, TP15.1 (1_1), U4.C1 (VDD), U14.1 (OUT)
+3.3V_DIG: C5.1, C18.1, C27.1, C31.1, C33.2, C34.1, C36.1, C38.1, C67.1, IC1.12 (VREFH/VDD_ANA), IC1.13 (VDD_1), IC1.29 (VDD_P3), IC1.48 (VDD_P3/VDD), IC1.60 (VDD_2), J5.1 (VCC), R18.2, R23.1, R24.1, R29.1, R32.1, TP13.1 (1_1), U3.5 (VIO), U4.B3 (VDDIO), U12.8 (SNS), U12.9 (OUT), U12.10 (OUT), U14.5 (EN), U14.8 (IN)
+3.3V_RF: C8.1, C9.1, JP1.1 (A), R13.1, R21.2, TP12.1 (1_1), U1.44 (VDD_3V3), U1.45 (VDD_3V3), U7.8 (SNS), U7.9 (OUT), U7.10 (OUT)
+3.7V: C3.1, C6.1, C22.1, R15.2, R25.2, TP14.1 (1_1), U7.1 (IN), U7.2 (IN), U7.3 (EN_UV), U8.8 (OUT), U8.9 (OUT), U12.1 (IN), U12.2 (IN), U12.3 (EN_UV)
+5V: C15.2, C21.1, C68.1, JP1.3 (B), R9.2, TP11.1 (1_1), U3.3 (VCC), U6.5 (VOUT), U8.17 (VIN), U8.18 (VIN), U9.5 (VOUT), U10.5 (VOUT), U13.5 (VOUT)
+5V_NXP: C10.1, J8.3 (+5V), J8.4 (+5V), J8.5 (+5V), J8.6 (+5V), U10.1 (vin), U10.3 (CE)
+5V_UART2: C11.1, TP3.1 (1_1), U13.1 (vin), U13.3 (CE)
/CAN1_RX: IC1.59 (P1_3), U3.4 (RXD)
/CAN1_TX: IC1.58 (P1_2), U3.1 (TXD)
/CAN_STATUS-led: IC1.57 (P1_1), R12.1
/EXTAL48M: C39.1, IC1.10 (P1_31), Y1.1
/Event_A: J1.3, J8.20 (P1_22/FC4_P2), U1.39 (EVENT_A)
/Event_B: U1.40 (EVENT_B)
/GPIO1: R10.1, U1.52 (GPIO1)
/GPIO2: U1.53 (GPIO2)
/Mag_SCL: IC1.34 (P3_27), R29.2, TP7.1 (1_1), U4.A3 (SCK)
/Mag_SDA: IC1.33 (P3_28), R32.2, TP8.1 (1_1), U4.A2 (SDA)
/NRST: C37.2, IC1.8 (P1_29), J5.3 (~RESET), SW3.1, SW3.1'
/PPS_O_1: IC1.32 (P3_29), J1.1, J8.16 (P1_9/I3C1_SCL/FC4_P1), R8.1, U1.42 (PPS1)
/PPS_O_2: U1.43 (PPS2)
/RST_IN: U1.7 (RST_IN)
/SCL: IC1.3 (P1_9), J7.2, R24.2
/SDA: IC1.2 (P1_8), J7.3, R23.2
/SWCLK: IC1.50 (P0_1), J5.4 (SWCLK)
/SWDIO: IC1.49 (P0_0), J5.2 (SWDIO)
/SWO: IC1.51 (P0_2), J5.6 (SWO)
/UART2_RX: IC1.14 (P2_0), TP4.1 (1_1)
/UART2_TX: IC1.15 (P2_1), TP5.1 (1_1)
/USB_DN: U1.13 (USB_DN), U2.5 (D-_out)
/USB_DP: U1.12 (USB_DP), U2.6 (D+_out)
/VANT: JP1.2 (C), U1.54 (VANT)
/XTAL48M: C40.1, IC1.9 (P1_30), Y1.3
/aux_ant: J11.1 (In), U1.5 (ANT_AUX)
/main_ant: J10.1 (In), U1.2 (ANT_MAIN)
/mosaic RX: IC1.35 (P3_15), U1.9 (RXD1)
/mosaic TX: IC1.36 (P3_14), U1.10 (TXD1)
/mosaic_CTS2: J4.5, J8.27 (P4_2/FC2_P2), U1.28 (CTD2)
/mosaic_RTS2: J4.4, J8.29 (P4_3/FC2_P3), U1.26 (RTS2)
/mosaic_RX2: J4.2, J8.23 (P4_1/FC2_P1), U1.29 (RXD2)
/mosaic_TX2: J4.3, J8.21 (P4_0/FC2_P0), U1.25 (TXD2)
FC_5V_U1: C1.1, J4.1, J7.1, U6.1 (vin), U6.3 (CE)
GND: C1.2, C2.2, C3.2, C4.2, C5.2, C6.2, C7.2, C8.2, C9.2, C10.2, C11.2, C15.1, C18.2, C20.2, C21.2, C22.2, C25.2, C26.2, C27.2, C31.2, C33.1, C34.2, C35.1, C36.2, C37.1, C38.2, C39.2, C40.2, C67.2, C68.2, C74.2, C75.1, C76.1, D1.1 (K), D2.1 (K), D3.2 (A), D5.1 (K), D6.1 (K), D11.3 (common), H1.1 (1_1), H2.1 (1_1), H3.1 (1_1), H4.1 (1_1), H5.1 (1_1), H6.1 (1_1), IC1.11 (VSS/VREFL), IC1.28 (VSS_1), IC1.47 (VSS_2), IC1.61 (VSS_3), J1.2, J3.A1 (GND), J3.A12 (GND__1), J3.B1 (GND__2), J3.B12 (GND__3), J4.6, J4.S1 (SHIELD), J4.S2 (SHIELD), J5.5 (GND), J6.4, J7.4, J8.1 (GND), J8.2 (GND), J8.7 (GND), J8.8 (GND), J8.12 (GND), J8.13 (GND), J8.15 (GND), J8.18 (GND), J8.19 (GND), J8.24 (GND), J8.25 (GND), J8.30 (GND), J8.31 (GND), J8.36 (GND), J8.37 (GND), J8.42 (GND), J8.43 (GND), J8.49 (GND), J8.50 (GND), J9.4, J10.2 (Ext), J11.2 (Ext), R6.1, R7.2, R11.1, R16.2, R19.1, R20.1, R22.1, R26.2, R34.2, SW3.2, SW3.2', TP6.1 (1_1), TP9.1 (1_1), U1.1 (GND), U1.3 (GND), U1.4 (GND), U1.6 (GND), U1.11 (GND), U1.17 (GND), U1.21 (GND), U1.27 (GND), U1.34 (GND), U1.41 (GND), U1.46 (GND), U1.49 (GND), U1.55 (GND), U1.56 (GND), U1.57 (GND), U1.58 (GND), U1.59 (GND), U1.60 (GND), U1.61 (GND), U1.62 (GND), U1.63 (GND), U1.64 (GND), U1.65 (GND), U1.66 (GND), U1.67 (GND), U1.68 (GND), U1.69 (GND), U1.70 (GND), U1.71 (GND), U1.72 (GND), U1.73 (GND), U1.74 (GND), U1.75 (GND), U1.76 (GND), U1.77 (GND), U1.78 (GND), U1.79 (GND), U1.80 (GND), U1.81 (GND), U1.82 (GND), U1.83 (GND), U1.84 (GND), U1.85 (GND), U1.86 (GND), U1.87 (GND), U1.88 (GND), U1.89 (GND), U1.90 (GND), U1.91 (GND), U1.92 (GND), U1.93 (GND), U1.94 (GND), U2.3 (GND), U3.2 (GND), U3.8 (STB), U3.9 (EP), U4.B1 (GND), U4.B2 (ADSEL), U4.C3 (BYPASS), U6.2 (VSS), U7.6 (GND), U7.11 (Thermal_Pad), U7.12 (GND), U7.13 (GND), U7.14 (GND), U7.15 (GND), U8.1 (PGND), U8.2 (PGND), U8.14 (AGND), U8.15 (AGND), U8.19 (PGND), U8.20 (PGND), U9.2 (VSS), U10.2 (VSS), U12.6 (GND), U12.11 (Thermal_Pad), U12.12 (GND), U12.13 (GND), U12.14 (GND), U12.15 (GND), U13.2 (VSS), U14.6 (GND), U14.9 (EP), Y1.2, Y1.4
unnamed: C75.2, R27.2, R28.1
unnamed: D1.2 (A), R13.2
unnamed: D2.2 (A), R12.2
unnamed: C20.1, D3.1 (K), J3.A4 (VBUS), J3.A9 (VBUS__1), J3.B4 (VBUS__2), J3.B9 (VBUS__3), L6.2
unnamed: D5.2 (A), R10.2
unnamed: D6.2 (A), R8.2
unnamed: C74.1, D11.1 (A1), J6.2, J9.2, L1.2, R30.1
unnamed: C76.2, D11.2 (A2), J6.3, J9.3, L1.3, R31.2
unnamed: IC1.25 (VDD_US_B), R26.1
unnamed: J3.A5 (CC1), R7.1
unnamed: J3.B5 (CC2), R6.2
unnamed: J3.A7 (DN1), J3.B7 (DN2), U2.2 (D-_in)
unnamed: J3.A6 (DP1), J3.B6 (DP2), U2.1 (D+_in)
unnamed: J6.1, J9.1
unnamed: R27.1, R30.2
unnamed: R28.2, R31.1
unnamed: U1.47 (REF_O), U1.48 (REF_I)
unnamed: U1.50 (VREF_I), U1.51 (VREF_O)
unnamed: L1.1, U3.7 (CANH)
unnamed: L1.4, U3.6 (CANL)
unnamed: C35.2, U4.C2 (CRST)
unnamed: R21.1, R22.2, U7.5 (FB_PG)
unnamed: C7.1, R20.2, U7.7 (NR_SS)
unnamed: R9.1, U8.11 (EN)
unnamed: R15.1, R16.1, U8.13 (FB)
unnamed: R25.1, U8.10 (OUT_SENSE)
unnamed: U8.4 (SW), U8.5 (SW), U8.6 (SW), U8.7 (SW)
unnamed: R18.1, R19.2, U12.5 (FB_PG)
unnamed: C4.1, R11.2, U12.7 (NR_SS)
unnamed: R17.2, R34.1, U14.4 (FB)
VBUS: C2.1, L6.1, U1.14 (USB_VBUS), U9.1 (vin), U9.3 (CE)

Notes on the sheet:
DF40TC(2.5)-50DS-0.4V(51)
Cross is made Here
Magnetometer
CAN connectors & transceiver
NXP MCU
LDO Mag 3v3 - 1V8
Connectors & Jumpers
LDO regulator DIG 3.7v-3.3v
Solder pads
mosaic-G5 P3H
Board to board connector - (Based on NXP pin)
LDO regulator RF 3.7v-3.3v
OUT
Red
Drive CANx_STB LOW to enable CAN transceiver
Buck converter 5-3.7v
Ideal Diode
Orange
USB C
300mA max per pin 5V = 1A max 3V3 = 500mA max 1V8 = 200A max
Green
SCT0_OUT9
Blue
Antenna
JTAG TC2030
LEDs
MountingHole
SCT0_IN3

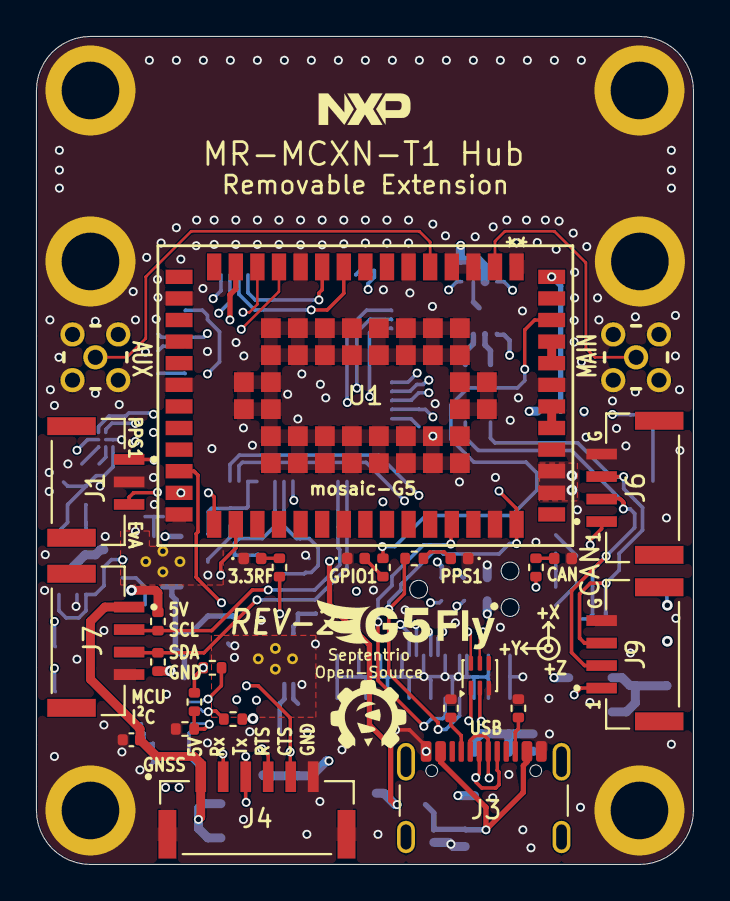
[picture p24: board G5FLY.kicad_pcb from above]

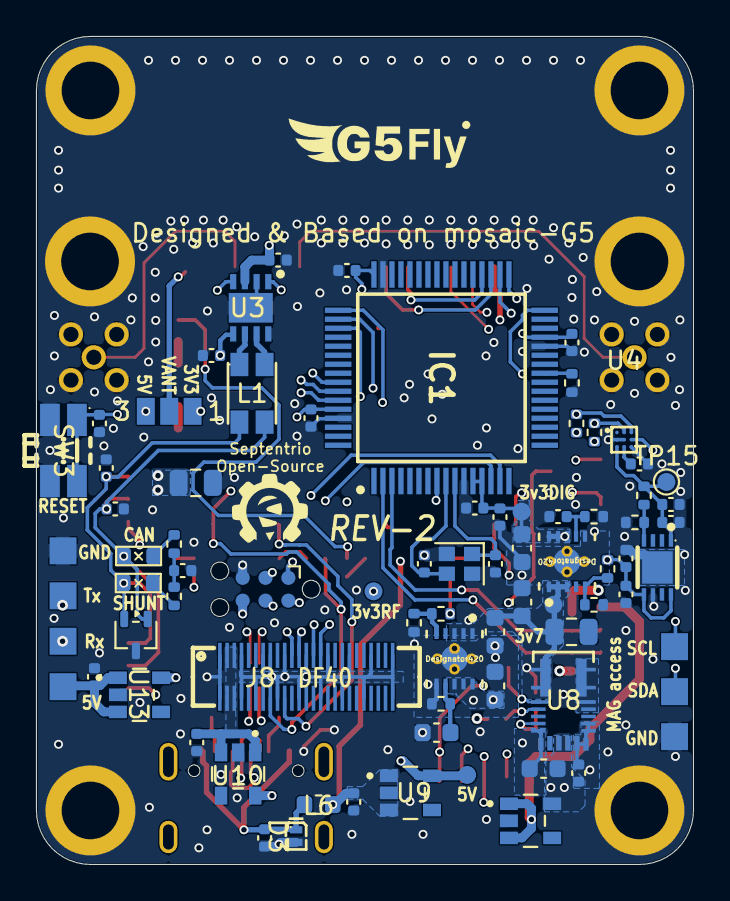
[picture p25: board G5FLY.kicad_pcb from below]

Board: 6 copper layers, 36.5 x 46.0 mm, 112 parts (79 on the bottom side), 69 nets.

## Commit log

2026-09-22 Import NXP project structure
    [Cube-orange-param-GPS-config.param, G5FLY.kicad_pcb, G5FLY.kicad_sch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]
2026-09-23 release: publish NXP hardware revision
    [Cube-orange-param-GPS-config.param, G5FLY.kicad_sch, G5Fly-DroneCan-param-node.param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]
